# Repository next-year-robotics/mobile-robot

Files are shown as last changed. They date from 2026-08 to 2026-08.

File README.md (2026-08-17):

# Mobile Robot

An open mobile robot platform for perception, navigation, manipulation, and simulation.

> Work in progress.

## Structure

- `hardware/` — Mechanical and electronic design
- `firmware/` — STM32 and micro-ROS firmware
- `software/` — ROS 2 packages and higher-level software

## License

- Software and firmware: Apache-2.0
- Hardware: CERN-OHL-S-2.0
- Documentation: CC BY 4.0

See [LICENSE.md](./LICENSE.md).

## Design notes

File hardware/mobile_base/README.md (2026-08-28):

# Mobile-base geometry handoff

This directory is the hardware-side source of truth for the mobile-base frame,
drive-wheel, and camera placement measurements.

## Files

- `robot_params.yaml` is the compact parameter set intended for
  `software/ros_pkgs/mr_description/config/robot_params.yaml`.
- `cad_measurements.yaml` preserves the CAD origin, axis mapping, raw bounding
  boxes, derived transforms, measurement provenance, and deferred outputs.

The `mr_description` ROS package did not exist in this repository when this
handoff was created, so the integration-ready parameters are kept here until
that package is added.

## Coordinate contract

`base_footprint` is the floor point directly below the drive-axle midpoint.
Robot `+x` is forward, `+y` is left, and `+z` is up. `base_link` is 50 mm
directly above `base_footprint`, at the drive-axle height.

The confirmed transforms are:

```text
base_footprint -> base_link:      [0.000,  0.000, 0.050] m
base_link -> camera optical:      [0.250,  0.000, 0.360] m
base_link -> left wheel centre:   [0.000, +0.132, 0.000] m
base_link -> right wheel centre:  [0.000, -0.132, 0.000] m
camera mount RPY:                 [0.0, 0.0, 0.0] deg
```

The camera optical centre is therefore 410 mm above the floor and 250 mm in
front of the drive axle. It is centred laterally and looks straight forward.

## Derived-value checks

```text
camera z from base_link = 0.410 - 0.050 = 0.360 m
half wheel separation   = 0.264 / 2       = 0.132 m
wheel side inset        = 0.400 / 2 - 0.132 = 0.068 m
```

The measured “70 mm from each side” description is treated as rounded. The
existing 264 mm nominal wheel-separation contract is authoritative.

## CAD scope

The inspected STEP currently contains the aluminium frame, caster mounting
plates, and four casters. It does not yet contain the two driven wheels,
motors, C920, or camera mount. Its aluminium-frame bounding dimensions are
450 x 400 x 368 mm; these values are used only for the RViz placeholder shape.

No mount-face offset is needed for TF because the lens optical centre was
provided directly. Generate visual meshes only after the missing hardware is
added to the final CAD. A SolidWorks URDF export can then be used to
cross-check joint origins, but it should not replace the frame and link-name
contract recorded here.

## Odometry values are deliberately separate

`robot_params.yaml` contains the nominal geometry (`0.050 m` radius and
`0.264 m` separation). Do not overwrite the calibrated effective values in
`software/ros_pkgs/mr_base/config/base_params.yaml`; those values serve wheel
odometry and are expected to differ from the nominal hardware geometry.

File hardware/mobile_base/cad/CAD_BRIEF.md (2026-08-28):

# Mobile-base CAD brief

- Model: independently authored mobile-base assembly with an aluminium-extrusion
  cart, four simplified swivel casters, two nominal hinge-spring drive modules,
  and two reusable drive-wheel occurrences.
- Task type: new assembly and secondary RViz mesh exports.
- Inputs: `../cad_measurements.yaml`, `../robot_params.yaml`, the measured envelope
  of `C:/cad_work/cart/02_assembly/cart_sim.STEP`, and the geometry/interface
  parameters in
  `C:/cad_work/cart/hinge_spring_A_2026-07-31/hinge_spring_A_core.py`.
- Copyright boundary: the reference STEP is measured and visually inspected but
  never imported by this generator. All exported BREP and mesh geometry is built
  from fresh build123d primitives. Purchased-item detail is represented by new
  envelopes rather than copied supplier geometry.
- Units: millimetres in CAD and STL; URDF applies a `0.001` mesh scale.
- Mass: measured complete-robot mass is `9.8 kg`. The STEP remains a geometric
  master without artificial material densities; URDF link inertials allocate
  `8.6 kg` to the static chassis, `0.5 kg` to each drive wheel, and `0.2 kg` to
  the camera so the modeled total is exactly `9.8 kg`.
- Coordinate convention: preserve the measured STEP coordinate system. CAD
  `+x/+y/+z` equals robot forward/left/up. The CAD origin remains the aluminium
  frame plan origin. `base_link` is at `[-25, 0, 43.482687] mm` in CAD.
- Overall aligned-caster envelope: `515.529602 x 400 x 456.517313 mm`, with
  `z=[-6.517313, 450] mm`.
- Frame envelope: `450 x 400 x 368 mm`, with `z=[82, 450] mm`.
- Lower frame plane: the four internal `井`-pattern rails and the four outer
  lower perimeter rails share centre `z=92 mm`, bottom `z=82 mm`, and top
  `z=102 mm`; no internal rail is raised above the perimeter plane.
- Caster alignment: all four caster-wheel rolling planes are parallel to the
  powered drive wheels and robot `+X`; front caster yaws are `0 deg` and rear
  caster yaws are `180 deg` for a symmetric fore/aft pose.
- Drive geometry: wheel radius `50 mm`, width `24 mm`, and centres at
  `[-25, +132, 43.482687] mm` and `[-25, -132, 43.482687] mm`.
- Spring-module intent: keep the nominal 150 x 30 x 3 mm rocker, 95 mm
  pivot-to-wheel X distance, 50.2 mm installed spring length, and simplified
  hinge, motor, shaft, adapter, spring-seat, and travel-stop envelopes. The
  lateral shaft stack is adapted to the authoritative 264 mm wheel track.
- Positioning/mating: the cart is the fixed assembly root. Each wheel is placed
  with a source-level revolute mate about global `+Y`; the relation labels match
  `left_wheel_joint` and `right_wheel_joint`.
- Paths: `mobile_base_cad.py` -> `mobile_base_cad.step`;
  `cart_frame_mesh.py` -> `cart_frame_mesh.step` and the package STL;
  `drive_wheel_mesh.py` -> `drive_wheel_mesh.step` and the reusable package STL.
- Validation targets: labeled assembly, exact outer/static and wheel bounding
  boxes, 264 mm wheel-centre spacing, source-level revolute relationships,
  positive-volume solids, saved multi-view snapshots, and metre-scaled URDF
  mesh dimensions without a 1000x error.
- Assumptions: caster and purchased drive hardware are geometry envelopes, not
  manufacturing replicas. The C920 housing is omitted from CAD; URDF uses the
  permitted box envelope at the measured optical-centre transform.

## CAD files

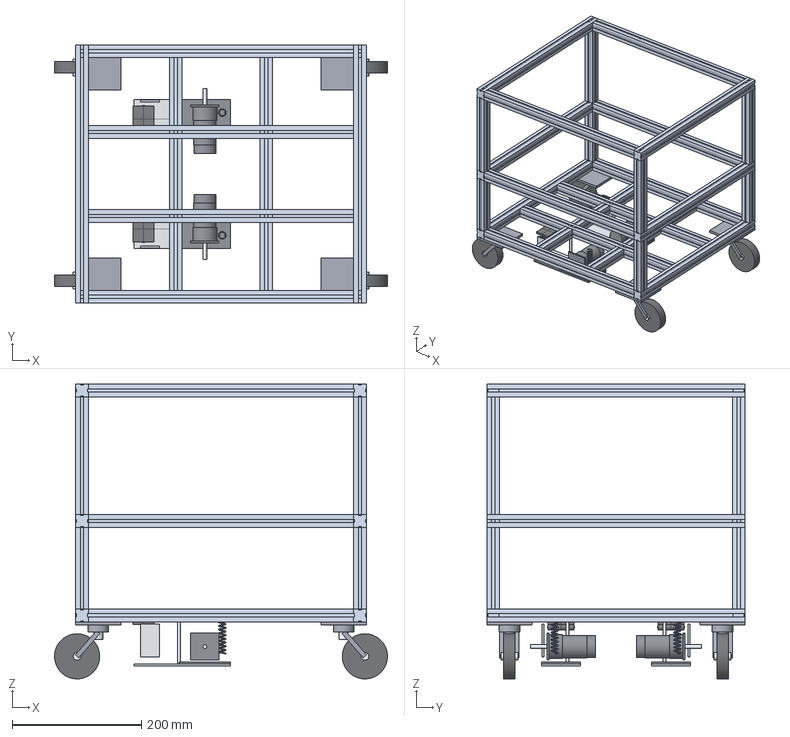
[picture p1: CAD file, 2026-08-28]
hardware/mobile_base/cad/cart_frame_mesh.step
515.5 x 400.0 x 456.5 mm
lower_left_x_rail
lower_right_x_rail
lower_front_y_rail
lower_rear_y_rail
upper_left_x_rail
upper_right_x_rail
upper_front_y_rail
upper_rear_y_rail
front_left_post
front_right_post
rear_left_post
rear_right_post
middle_left_x_rail
middle_right_x_rail
middle_front_y_rail
middle_rear_y_rail
lower_inner_x_rail_1
lower_inner_x_rail_2
lower_inner_y_rail_1
lower_inner_y_rail_2
front_left_caster_mount_plate
front_left_caster_swivel_bearing
front_left_caster_swivel_stem
front_left_caster_fork_arm_a
front_left_caster_fork_arm_b
front_left_caster_wheel
front_left_caster_axle
rear_right_caster_mount_plate
rear_right_caster_swivel_bearing
rear_right_caster_swivel_stem
rear_right_caster_fork_arm_a
rear_right_caster_fork_arm_b
rear_right_caster_wheel
rear_right_caster_axle
rear_left_caster_mount_plate
rear_left_caster_swivel_bearing
rear_left_caster_swivel_stem
rear_left_caster_fork_arm_a
rear_left_caster_fork_arm_b
rear_left_caster_wheel
rear_left_caster_axle
front_right_caster_mount_plate
front_right_caster_swivel_bearing
front_right_caster_swivel_stem
front_right_caster_fork_arm_a
front_right_caster_fork_arm_b
front_right_caster_wheel
front_right_caster_axle
left_rocker_1_150x30x3
left_rocker_2_150x30x3
left_hinge_1_fixed_leaf
left_hinge_1_moving_leaf
left_hinge_1_barrel
left_hinge_1_pin
left_hinge_2_fixed_leaf
left_hinge_2_moving_leaf
left_hinge_2_barrel
left_hinge_2_pin
left_WM12_60_spring_envelope
left_travel_stop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

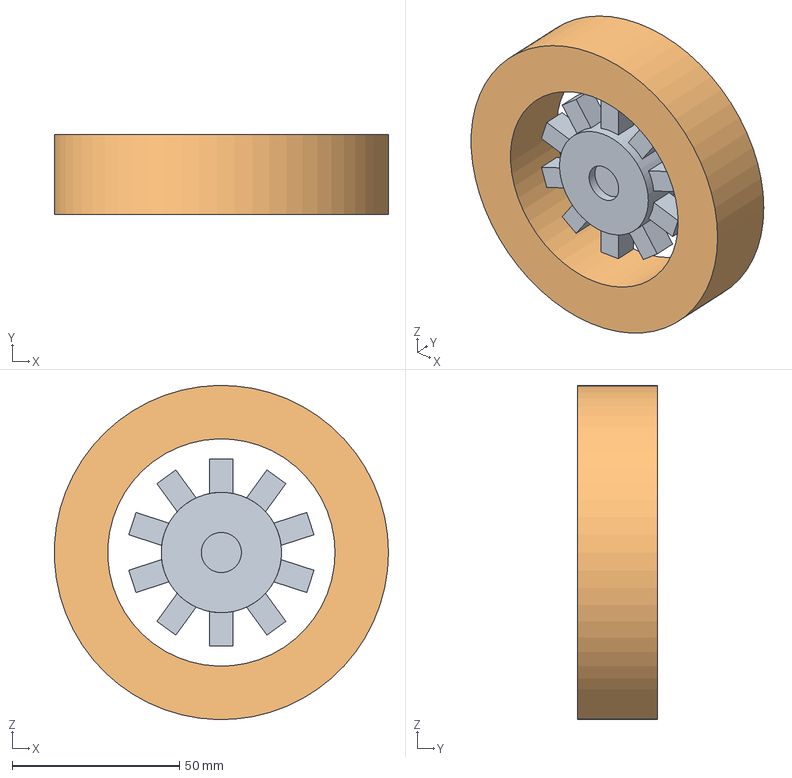
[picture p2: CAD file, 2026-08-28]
hardware/mobile_base/cad/drive_wheel_mesh.step
99.9 x 24.0 x 100.0 mm

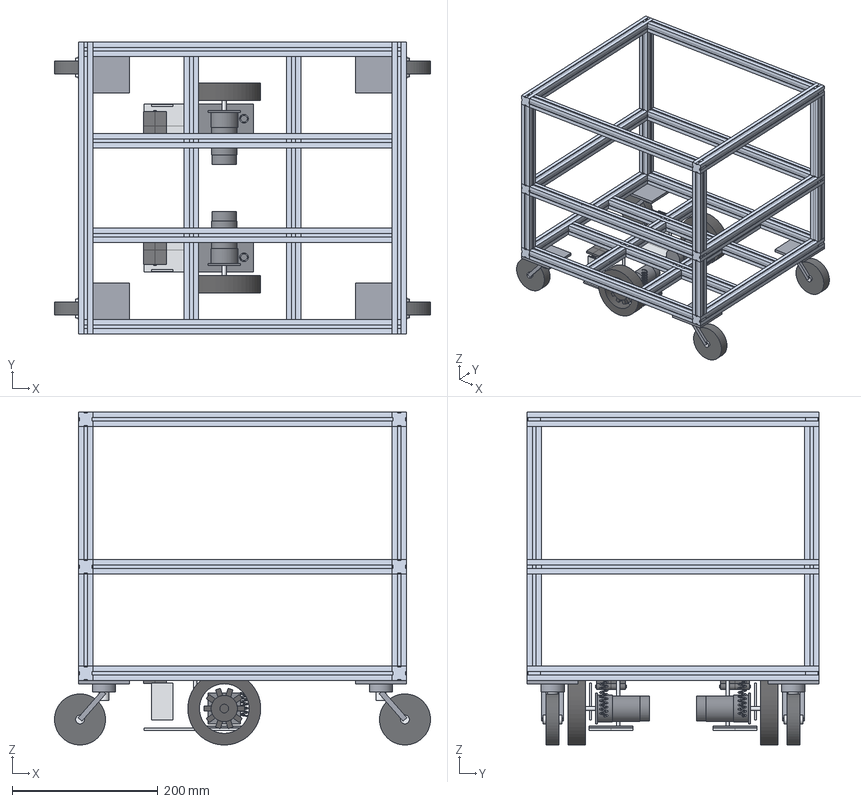
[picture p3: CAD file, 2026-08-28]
hardware/mobile_base/cad/mobile_base_cad.step
515.5 x 400.0 x 456.5 mm
lower_left_x_rail
lower_right_x_rail
lower_front_y_rail
lower_rear_y_rail
upper_left_x_rail
upper_right_x_rail
upper_front_y_rail
upper_rear_y_rail
front_left_post
front_right_post
rear_left_post
rear_right_post
middle_left_x_rail
middle_right_x_rail
middle_front_y_rail
middle_rear_y_rail
lower_inner_x_rail_1
lower_inner_x_rail_2
lower_inner_y_rail_1
lower_inner_y_rail_2
front_left_caster_mount_plate
front_left_caster_swivel_bearing
front_left_caster_swivel_stem
front_left_caster_fork_arm_a
front_left_caster_fork_arm_b
front_left_caster_wheel
front_left_caster_axle
rear_right_caster_mount_plate
rear_right_caster_swivel_bearing
rear_right_caster_swivel_stem
rear_right_caster_fork_arm_a
rear_right_caster_fork_arm_b
rear_right_caster_wheel
rear_right_caster_axle
rear_left_caster_mount_plate
rear_left_caster_swivel_bearing
rear_left_caster_swivel_stem
rear_left_caster_fork_arm_a
rear_left_caster_fork_arm_b
rear_left_caster_wheel
rear_left_caster_axle
front_right_caster_mount_plate
front_right_caster_swivel_bearing
front_right_caster_swivel_stem
front_right_caster_fork_arm_a
front_right_caster_fork_arm_b
front_right_caster_wheel
front_right_caster_axle
left_rocker_1_150x30x3
left_rocker_2_150x30x3
left_hinge_1_fixed_leaf
left_hinge_1_moving_leaf
left_hinge_1_barrel
left_hinge_1_pin
left_hinge_2_fixed_leaf
left_hinge_2_moving_leaf
left_hinge_2_barrel
left_hinge_2_pin
left_WM12_60_spring_envelope
left_travel_stop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

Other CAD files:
software/ros_pkgs/mr_description/meshes/cart_frame.stl
software/ros_pkgs/mr_description/meshes/drive_wheel.stl

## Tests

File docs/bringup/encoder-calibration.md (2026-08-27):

# 엔코더 브링업 및 바퀴 틱 수 실측

완료: 2026-08-20

## 1. 목적

1. TIM2/TIM3 encoder mode가 잘 동작하는가?
2. 바퀴 1회전당 틱 수(`ticks_per_wheel_revolution`)는 실제로 얼마인가?

## 2. 구성

| 항목 | 값 |
|---|---|
| 모터 | JGB37-520 × 2 |
| 엔코더 | 홀 방식, 채널당 공칭 11 pulse/rev (모터축 기준) |
| 왼쪽 A/B | PA6 / PA7 — TIM3 encoder |
| 오른쪽 A/B | PA0 / PA1 — TIM2 encoder |
| Encoder Mode | TI1 and TI2 (×4 체배) |
| ARR | 65535 (두 타이머 모두 16-bit 범위로 통일) |
| 입력 필터 IC1F/IC2F | 4 |
| A/B 외부 풀업 | 10 kΩ → 3V3 (4개) |
| 엔코더 전원 | NUCLEO 3V3 실측 3.307 V |

## 3. 동작 검증

| 시험 | 기대값 | 실측 | 결과 |
|---|---|---|---|
| 정지 60초 자발 카운트 | 0 tick | 좌 0 / 우 0 | **PASS** |
| 왼쪽만 회전 시 오른쪽 변화 | 0 tick | 0 | **PASS** |
| 오른쪽만 회전 시 왼쪽 변화 | 0 tick | 0 | **PASS** |
| 왼쪽 정/역 1회전 복귀 | ±2 tick | 0 tick | **PASS** |
| 오른쪽 정/역 1회전 복귀 | ±2 tick | 1 tick | **PASS** |

전진 방향 원시 부호는 왼쪽 +, 오른쪽 - 

## 4. 바퀴 10회전 틱 수 실측

바퀴에 표시점을 두고 정확히 10회전시켜 누적 틱 차이를 잰다.

| 바퀴 | 방향 | 1 | 2 | 3 | 4 | 5 | 평균 tick/rev | 표준편차 | RSD |
|---|---|---:|---:|---:|---:|---:|---:|---:|---:|
| 왼쪽 | 정방향 | 2473.9 | 2473.8 | 2476.2 | 2474.7 | 2475.8 | **2474.88** | 1.09 | **0.044 %** |
| 왼쪽 | 역방향 | 2482.0 | 2480.7 | 2475.3 | 2476.7 | 2475.9 | **2478.12** | 3.03 | **0.122 %** |
| 오른쪽 | 정방향 | 2473.7 | 2475.0 | 2473.1 | 2475.7 | 2474.3 | **2474.36** | 1.03 | **0.042 %** |
| 오른쪽 | 역방향 | 2475.6 | 2474.1 | 2475.5 | 2474.6 | 2473.6 | **2474.68** | 0.87 | **0.035 %** |

### 확정값

| 항목 | 값 |
|---|---|
| `ticks_per_wheel_revolution` 왼쪽 | **2476.5** |
| `ticks_per_wheel_revolution` 오른쪽 | **2474.5** |
| 좌우 통합 | **2475.5** |

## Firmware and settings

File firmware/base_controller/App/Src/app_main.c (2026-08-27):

/**
  ******************************************************************************
  * @file    app_main.c
  * @brief   LegacyIoTask orchestration. ASCII 수신/파싱/ACK/telemetry만 맡는다.
  * @note    정책·파싱 계산은 전부 순수 모듈에 있다. 이 파일은 순서만 정한다.
  *          레지스터는 platform_stm32 adapter를 통해서만 만진다. TIM1/CCR/MOE는
  *          여기서 건드리지 않는다. 모터 출력의 정상 경로 소유자는 ControlTask다.
  *
  *          한 바퀴의 순서는 안전이 먼저다. 자세한 단계는 app_step()에 적어 두었다.
  ******************************************************************************
  */
#include "app_main.h"

#include "app_config.h"
#include "app_link.h"
#include "control_ack.h"
#include "control_types.h"
#include "line_builder.h"
#include "motor_output.h"
#include "motor_safety.h"
#include "platform_stm32.h"
#include "protocol_ascii.h"
#include "rx_ring.h"

static rx_ring_t  g_rx;
static protocol_t g_proto;

/* 송신 버퍼. 송신은 전부 이 task에서만 하므로 하나를 돌려 쓴다. */
static char g_tx_buffer[TX_LINE_CAP];

static uint32_t g_last_report_ms;

/* `spd` 텔레메트리 스위치. 기본은 꺼짐이다. 이 줄을 해석하지 않는 호스트 도구가 있으므로
   기본으로 켜 두면 그쪽 파싱이 깨진다. */
static bool g_spd_enabled;

/* ControlTask status에서 관측한 워치독 만료 edge. 변화가 보일 때만 `wd` 한 줄이 나간다. */
static uint32_t g_wd_seq_seen;

/* 발행한 command sequence. 0은 "없음"이라 1부터 쓴다. */
static uint32_t g_cmd_seq;

/* ISR이 올리고 task가 관측하는 계측값. */
static volatile uint32_t g_uart_error_count;
static volatile uint32_t g_uart_error_last;
static volatile uint32_t g_rx_rearm_fail_isr;
static volatile uint32_t g_rx_overflow_count;
/* RX overflow/UART error마다 ISR이 증가시킨다. ISR은 동시에 ControlTask에 urgent
   STOP도 건다. task는 epoch 변화를 보면 링을 통째로 비우고 다음 개행까지 parser를
   poison한다. */
static volatile uint32_t g_rx_fault_epoch;
static uint32_t g_rx_fault_seen;
static uint32_t g_rx_rearm_fail_run;
static uint32_t g_tx_fail_count;
static uint32_t g_tx_build_fail_count;
static uint32_t g_cmd_accepted_count;
static uint32_t g_cmd_timeout_count;
static uint32_t g_cmd_seq_mismatch_count;
static uint32_t g_cmd_rejected_count;

/* ------------------------------------------------------------------------- */
/* ISR 진입점                                                                 */
/* ------------------------------------------------------------------------- */

void app_on_rx_byte(uint8_t byte)
{
  if (!rx_ring_push(&g_rx, byte))
  {
    g_rx_overflow_count++;
    g_rx_fault_epoch++;
    /* CCR을 여기서 직접 쓰지 않는다. 최고 우선순위 ControlTask가 ISR 복귀 즉시
       선점해 출력을 0으로 만든다. */
    app_link_urgent_stop_from_isr(MOTOR_FAULT_NONE);
    /* 링 폐기와 parser poison은 IO task의 일이다. poll timeout을 기다리지 않고
       바로 깨워 재동기화를 앞당긴다. */
    app_link_notify_io_from_isr();
    return;
  }

  /* 프레임 경계에서만 깨운다. 230400 8N1에서 바이트마다 깨우면 notification이 초당
     2만 번을 넘는다. 그만큼은 전부 ISR/문맥전환 오버헤드가 된다. */
  if (byte == (uint8_t)'\n')
  {
    app_link_notify_io_from_isr();
  }
}

void app_on_uart_error(uint32_t error_code)
{
  /* HAL의 ORE 복구/재무장 경계에서는 ErrorCode가 이미 clear된 callback이 뒤따를 수
     있다. 마지막 유효 FE/NE/ORE 진단값을 0으로 덮어쓰지 않는다. */
  if (error_code != 0U)
  {
    g_uart_error_last = error_code;
  }
  g_uart_error_count++;
  g_rx_fault_epoch++;
  app_link_urgent_stop_from_isr(MOTOR_FAULT_NONE);
  app_link_notify_io_from_isr();
}

void app_on_rx_rearm_failed(void)
{
  g_rx_rearm_fail_isr++;
}

/* ------------------------------------------------------------------------- */
/* 송신                                                                       */
/* ------------------------------------------------------------------------- */

/**
  * @brief  한 줄을 조립해 내보낸다. 실패는 계측하고 안전 상태로 넘어간다.
  * @note   빌더가 capacity를 실제로 검사하므로 넘치는 줄은 송신되지 않는다. 송신
  *         실패는 치명 경로다. platform_motor_kill()은 RTOS와 무관하게 즉시 부를 수
  *         있는 유일한 예외다. 그 뒤 ControlTask에도 fault를 래치시켜 이후 명령을
  *         `err`로 만든다.
  */
static void send_line(const char *tag, const int64_t *values, size_t count)
{
  size_t offset;
  size_t length;

  if (!line_build(g_tx_buffer, sizeof(g_tx_buffer), tag, values, count,
                  &offset, &length))
  {
    g_tx_build_fail_count++;
    platform_motor_kill();
    app_link_urgent_stop(MOTOR_FAULT_TX_BUILD);
    return;
  }

  if (!platform_uart_send(&g_tx_buffer[offset], length))
  {
    g_tx_fail_count++;
    platform_motor_kill();
    app_link_urgent_stop(MOTOR_FAULT_TX);
  }
}

static void send_err(uint32_t now_ms)
{
  int64_t value = (int64_t)now_ms;

  send_line("err", &value, 1U);
}

/* ------------------------------------------------------------------------- */
/* 수신                                                                       */
/* ------------------------------------------------------------------------- */

/** @brief ISR이 새 RX 손상을 기록했는가 (아직 동기화하지 않은 epoch가 있는가). */
static bool rx_fault_pending(void)
{
  return g_rx_fault_epoch != g_rx_fault_seen;
}

/**
  * @brief  ISR이 남긴 손상 신호를 프로토콜 상태기계에 반영한다.
  * @note   기존 큐에는 오류 위치보다 앞선 newline이 있을 수 있다. 큐 전체를 버린 뒤
  *         fault 이후 새로 도착한 newline에서만 parser가 재동기화되게 한다.
  */
static bool sync_rx_faults(void)
{
  uint32_t epoch;
  uint32_t critical_state = platform_critical_enter();

  epoch = g_rx_fault_epoch;
  if (epoch == g_rx_fault_seen)
  {
    platform_critical_exit(critical_state);
    return false;
  }

  /* 오류 바이트보다 앞에 있던 newline에서 너무 일찍 재동기화되는 일을 막기 위해
     현재 큐를 전부 버린다. critical section 안이라 ISR 생산자와 head/tail이 섞이지 않는다. */
  rx_ring_discard_all(&g_rx);
  g_rx_fault_seen = epoch;
  platform_critical_exit(critical_state);

  protocol_poison(&g_proto);

  /* ISR이 이미 걸었지만 여기서 한 번 더 확정한다. 멱등이다. task 문맥에서 뒤늦게
     발견한 epoch에도 정지가 반드시 따라붙게 한다. */
  app_link_urgent_stop(MOTOR_FAULT_NONE);
  return true;
}

/**
  * @brief  수신이 풀려 있으면 다시 건다. ErrorCallback이 놓친 경우의 그물이다.
  */
static void rx_rearm_if_needed(void)
{
  if (platform_uart_rx_is_armed())
  {
    g_rx_rearm_fail_run = 0U;
    return;
  }

  if (platform_uart_rx_arm())
  {
    g_rx_rearm_fail_run = 0U;
    return;
  }

  g_rx_rearm_fail_run++;
  if (g_rx_rearm_fail_run >= CMD_RX_REARM_FAIL_LIMIT)
  {
    platform_motor_kill();
    app_link_urgent_stop(MOTOR_FAULT_RX_REARM);
  }
}

/** @brief ASCII 명령 종류를 ControlTask의 지령 종류로 옮긴다. */
static control_cmd_kind_t control_kind_of(proto_cmd_kind_t kind)
{
  if (kind == PROTO_CMD_DUTY)
  {
    return CONTROL_CMD_DUTY;
  }
  if (kind == PROTO_CMD_VEL)
  {
    return CONTROL_CMD_VEL;
  }
  return CONTROL_CMD_STOP;
}

/**
  * @brief  수락된 명령을 ControlTask에 넘기고 적용 결과를 받은 뒤에만 ACK한다.
  * @note   `ok`는 "queue에 넣었다"가 아니라 "이 sequence의 값이 CCR에 반영됐다"는
  *         뜻이다. 그래서 stop도 출력이 0이 된 뒤에 ACK된다. `spd`만 예외다.
  *         ControlTask로 가지 않는 설정 명령이라 여기서 끝난다.
  */
static void command_accept(const proto_command_t *cmd, uint32_t now_ms)
{
  control_command_t out;
  control_apply_result_t result;
  control_ack_t ack;
  bool received;
  int64_t values[3];
  uint32_t critical_state;

  out.seq = g_cmd_seq + 1U;
  out.kind = control_kind_of(cmd->kind);
  out.left = cmd->left;
  out.right = cmd->right;
  out.accepted_ms = now_ms;
  out.deadline_ms = now_ms + CMD_WATCHDOG_MS;

  /* RX fault ISR이 판정과 게시 사이에 끼어 손상된 프레임의 명령이 나가지 못하게
     짧게 막는다. 여기서 걸리면 이 줄은 실행하지 않는다. */
  critical_state = platform_critical_enter();
  if (rx_fault_pending())
  {
    platform_critical_exit(critical_state);
    (void)sync_rx_faults();
    send_err(now_ms);
    return;
  }
  platform_critical_exit(critical_state);

  if (cmd->kind == PROTO_CMD_SPD)
  {
    /* 설정 명령이다. 워치독을 먹이지 않는다. 설정을 반복해서 모터를 계속 살려두는
       경로를 막기 위해서다. ControlTask의 mailbox에도 들어가지 않으므로 command
       sequence도 소비하지 않는다. ACK 형식은 그대로 두고 상태값 하나를 두 번
       싣는다. */
    g_spd_enabled = (cmd->left != 0);
    values[0] = (int64_t)now_ms;
    values[1] = (int64_t)cmd->left;
    values[2] = (int64_t)cmd->left;
    send_line("ok", values, 3U);
    return;
  }

  g_cmd_seq = out.seq;

  if (!app_link_post_command(&out))
  {
    send_err(now_ms);
    return;
  }
  g_cmd_accepted_count++;

  received = app_link_wait_applied(out.seq, CMD_APPLY_TIMEOUT_MS, &result);

  /* 적용된 뒤에 손상이 들어왔다면 출력은 이미 다시 0이다. 그 duty를 ok로 보고하지 않는다. */
  ack = control_ack_decide(received, out.seq, &result, rx_fault_pending());

  switch (ack)
  {
    case CONTROL_ACK_OK:
      values[0] = (int64_t)result.applied_ms;
      values[1] = (int64_t)result.left;
      values[2] = (int64_t)result.right;
      send_line("ok", values, 3U);
      return;

    case CONTROL_ACK_ERR_TIMEOUT:
      g_cmd_timeout_count++;
      break;

    case CONTROL_ACK_ERR_SEQ:
      g_cmd_seq_mismatch_count++;
      break;

    case CONTROL_ACK_ERR_REJECTED:
    case CONTROL_ACK_ERR_RX_FAULT:
    default:
      g_cmd_rejected_count++;
      break;
  }

  send_err(now_ms);
}

/**
  * @brief  수신 링을 소비하며 줄이 완성될 때마다 해석한다.
  * @note   바이트 수와 줄 수에 명시적 상한이 있다. 호스트가 짧은 오류 줄을 최고속으로
  *         퍼부어도 이 함수가 telemetry나 워치독 통지를 굶길 수 없다. 낮은 우선순위라
  *         100 Hz ControlTask를 지연시킬 수도 없다.
  */
static void command_poll(uint32_t now_ms)
{
  uint32_t bytes = 0U;
  uint32_t lines = 0U;

  while ((bytes < CMD_POLL_MAX_BYTES) && (lines < CMD_POLL_MAX_LINES))
  {
    proto_command_t cmd;
    proto_event_t event;
    uint8_t byte;

    if (sync_rx_faults())
    {
      /* 링 전체를 비웠다. 다음 loop에서 fault 이후 새 바이트를 기다린다. */
      break;
    }

    if (!rx_ring_pop(&g_rx, &byte))
    {
      break;
    }
    bytes++;

    event = protocol_push(&g_proto, (char)byte, &cmd);
    if (event == PROTO_EVENT_NONE)
    {
      continue;
    }

    lines++;
    if (event == PROTO_EVENT_COMMAND)
    {
      command_accept(&cmd, now_ms);
    }
    else
    {
      /* 거절한 줄은 워치독을 갱신하지 않는다. */
      send_err(now_ms);
    }
  }
}

/* ------------------------------------------------------------------------- */
/* 진입점                                                                     */
/* ------------------------------------------------------------------------- */

bool app_init(void)
{
  /* 수신 인터럽트가 살아나기 전에 소비 측 상태를 확정한다. */
  rx_ring_init(&g_rx);
  protocol_init(&g_proto);
  g_uart_error_count = 0U;
  g_uart_error_last = 0U;
  g_rx_rearm_fail_isr = 0U;
  g_rx_overflow_count = 0U;
  g_rx_fault_epoch = 0U;
  g_rx_fault_seen = 0U;
  g_rx_rearm_fail_run = 0U;
  g_tx_fail_count = 0U;
  g_tx_build_fail_count = 0U;
  g_cmd_accepted_count = 0U;
  g_cmd_timeout_count = 0U;
  g_cmd_seq_mismatch_count = 0U;
  g_cmd_rejected_count = 0U;
  g_cmd_seq = 0U;
  g_wd_seq_seen = 0U;
  g_spd_enabled = false;

  if (!platform_init())
  {
    return false;
  }

  g_last_report_ms = platform_now_ms();
  return true;
}

void app_step(void)
{
  uint32_t now_ms = platform_now_ms();
  control_status_t status;

  /* 1. 안전이 먼저다. RX 손상이 있으면 이전 큐를 폐기하고 출력 0을 확정시킨다. */
  (void)sync_rx_faults();

  /* 2. 링크 유지. */
  if (g_rx_rearm_fail_isr != 0U)
  {
    g_rx_rearm_fail_isr = 0U;
    g_rx_rearm_fail_run++;
  }
  rx_rearm_if_needed();

  /* 3. 상한이 있는 명령 처리. */
  command_poll(now_ms);

  if (!app_link_get_status(&status))
  {
    return;
  }

  /* 4. 워치독 만료 통지. ControlTask가 출력 0을 반영한 뒤에만 edge가 올라간다. */
  if (status.wd_seq != g_wd_seq_seen)
  {
    int64_t value = (int64_t)status.wd_ms;

    g_wd_seq_seen = status.wd_seq;
    send_line("wd", &value, 1U);
  }

  /* 5. 50 Hz 텔레메트리. 누적 int64 의미를 그대로 유지한다. */
  if ((uint32_t)(now_ms - g_last_report_ms) >= TICKS_REPORT_PERIOD_MS)
  {
    int64_t values[5];

    g_last_report_ms += TICKS_REPORT_PERIOD_MS;
    values[0] = (int64_t)now_ms;
    values[1] = status.ticks_left;
    values[2] = status.ticks_right;
    send_line("ticks", values, 3U);

    /* 튜닝용 스트림. 목표와 포화 플래그는 넣지 않는다. 목표는 ok가 이미 알려줬다.
       적분기와 포화는 SWD로 g_rtos_metrics에서 본다. 값을 늘리면 최악 줄이
       TX_LINE_CAP을 넘어 UART_TX_TIMEOUT_MS 여유까지 다시 잡아야 한다. */
    if (g_spd_enabled)
    {
      values[1] = (int64_t)status.measured_tps_left;
      values[2] = (int64_t)status.duty_left_pm;
      values[3] = (int64_t)status.measured_tps_right;
      values[4] = (int64_t)status.duty_right_pm;
      send_line("spd", values, 5U);
    }
  }
}

void app_get_io_metrics(app_io_metrics_t *out)
{
  out->rx_overflow_count = g_rx_overflow_count;
  out->uart_error_count = g_uart_error_count;
  out->uart_error_last = g_uart_error_last;
  out->rx_rearm_fail_count = g_rx_rearm_fail_run;
  out->tx_fail_count = g_tx_fail_count;
  out->tx_build_fail_count = g_tx_build_fail_count;
  out->cmd_accepted_count = g_cmd_accepted_count;
  out->cmd_timeout_count = g_cmd_timeout_count;
  out->cmd_seq_mismatch_count = g_cmd_seq_mismatch_count;
  out->cmd_rejected_count = g_cmd_rejected_count;
}

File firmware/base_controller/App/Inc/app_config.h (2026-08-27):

/**
  ******************************************************************************
  * @file    app_config.h
  * @brief   펌웨어 확정 상수. HAL/RTOS에 의존하지 않는다.
  * @note    순수 모듈과 STM32 adapter가 함께 쓰는 헤더다. 여기에 HAL 헤더나
  *          main.h를 들이면 host 단위 테스트가 깨진다.
  ******************************************************************************
  */
#ifndef APP_CONFIG_H
#define APP_CONFIG_H

#include <stdint.h>

/* ---- 주기 ---- */
#define LD2_TOGGLE_PERIOD_MS      500U
#define ENCODER_SAMPLE_PERIOD_MS   10U  /* == CONTROL_PERIOD_MS. ControlTask가 샘플한다. */
#define TICKS_REPORT_PERIOD_MS     20U  /* 50 Hz */

/* ---- RTOS 실행 구조 ---- */

/* TIM6가 만드는 control tick. .ioc의 TIM6 8399/99(84 MHz/8400/100)와 같아야 한다. */
#define CONTROL_RATE_HZ           100U
#define CONTROL_PERIOD_MS          10U

/* native FreeRTOS numeric priority다. FreeRTOSConfig.h의 configMAX_PRIORITIES=56은
   ST CMSIS-RTOS v2 wrapper의 compile-time 요구값일 뿐이고 아래 값과 무관하다. */
#define TASK_PRIO_CONTROL           5U
#define TASK_PRIO_HEALTH            4U
#define TASK_PRIO_LEGACY_IO         2U

/* 길이 단위는 StackType_t word다 (1 word = 4 B). CMSIS osThreadAttr_t의 stack_size는
   byte라 값이 다르다. 이 프로젝트는 task를 native xTaskCreateStatic으로만 만들므로
   전부 word로 읽는다. */
#define TASK_STACK_WORDS_CONTROL   384U  /* 1,536 B */
#define TASK_STACK_WORDS_HEALTH    256U  /* 1,024 B */
#define TASK_STACK_WORDS_IO        512U  /* 2,048 B */
#define TASK_STACK_WORDS_IDLE      256U  /* 1,024 B */

#define HEALTH_PERIOD_MS           50U

/* HIL 전용 build option. 평소에는 0이다. CMake의 -DIWDG_STALL_TEST=ON일 때만
   ControlTask 정지 주입 hook을 컴파일한다. */
#ifndef IWDG_STALL_TEST
#define IWDG_STALL_TEST              0
#endif

/* HIL 전용 build option. CMake의 -DU3_SMOKE_TEST=ON일 때만 SmokeTask와 u3_smoke.c가
   들어간다. production image에는 USART1로 한 바이트도 나가지 않는다. */
#ifndef U3_SMOKE_TEST
#define U3_SMOKE_TEST                0
#endif

/* SmokeTask는 가장 낮은 우선순위다. 시험 트래픽이 제어·관측·레거시 IO 중 어느 것도
   지연시킬 수 없어야 "제어는 그대로"라는 전제가 성립한다. */
#define TASK_PRIO_SMOKE             1U
#define TASK_STACK_WORDS_SMOKE    384U  /* 1,536 B */

/* USART1 DMA 링을 긁는 주기. 보드레이트가 올라가도 이 주기만 지키면 링이 넘치지 않는다. */
#define U3_SMOKE_POLL_MS            1U

/* T 스트림 주기. `/joint_states` 계약과 같은 50 Hz로 두어 실제 부하를 흉내 낸다. */
#define U3_STREAM_PERIOD_MS        20U

/* 한 주기에 긁어 갈 최대 바이트. 3 Mbaud의 1 ms 분량(약 300 B)보다 커야 한다. */
#define U3_SMOKE_READ_CHUNK       512U

/* 보드레이트 스윕 안전망. 속도를 바꾼 뒤 이 시간 안에 유효한 줄이 하나도 오지 않으면
   기본 속도로 되돌린다. 되돌리지 않으면 실패한 단계마다 보드 리셋이 필요하다.

   `.ioc`의 `USART1.BaudRate`와 같아야 한다. 갈리면 자동 복귀가 엉뚱한 속도로 가서
   링크가 살아나지 않는다. */
#define U3_BAUD_DEFAULT        921600U
#define U3_BAUD_REVERT_MS        5000U
/* ACK를 보낸 뒤 호스트가 자기 포트를 다시 여는 데 주는 시간. */
#define U3_BAUD_ACK_SETTLE_MS      50U

/* LegacyIoTask는 개행 notification으로 깨어난다. 이 timeout은 telemetry/워치독
   통지/재무장을 위한 그물이다. 명령 지연이 아니라 주기 작업의 jitter 상한이다. */
#define LEGACY_IO_POLL_MS           2U

/* ControlTask가 명령을 반영하고 결과를 돌려줄 때까지 기다리는 상한. ControlTask는
   최고 우선순위라 정상적으로는 게시 즉시 선점해 결과가 이미 와 있다. 이 시간을
   넘기면 적용 근거가 없으므로 err다. */
#define CMD_APPLY_TIMEOUT_MS       30U

/* HealthTask가 control heartbeat 정체로 보고 IWDG refresh를 중단하는 한계. */
#define HEALTH_HEARTBEAT_STALL_MS 100U

/* ---- micro-ROS ---- */

/* CMake의 -DMICRO_ROS=ON일 때만 MicroRosTask와 libmicroros.a가 들어간다.
   U3_SMOKE_TEST와는 동시에 켤 수 없다. 둘 다 USART1의 소유자를 자처한다. */
#ifndef MICRO_ROS
#define MICRO_ROS                    0
#endif

/* ControlTask보다 낮고 LegacyIoTask보다 높다.
     - ControlTask(P5)보다 낮아야 하는 이유: micro-ROS는 blocking 송신과 상한이
       분명치 않은 executor를 품고 있다. 100 Hz 제어를 막을 수 없어야 한다.
     - HealthTask(P4)보다 낮아야 하는 이유: reconnect storm 중에도 IWDG는 계속
       먹어야 한다.
     - LegacyIoTask(P2)보다 높아야 하는 이유: 이제 실제 주행 명령이 이 경로로
       온다. 디버그용 ASCII 텔레메트리가 /cmd_vel을 밀어내면 안 된다. */
#define TASK_PRIO_MICRO_ROS         3U

/* rcl/rclc의 호출 깊이가 있어 LegacyIoTask보다 넉넉히 잡는다. 실제 사용량은
   HealthTask가 재는 stack high-water mark로 확인하고 줄인다. */
#define TASK_STACK_WORDS_MICRO_ROS 1536U  /* 6,144 B */

/* MicroRosTask 한 바퀴의 상한. 이 주기가 곧 `/joint_states` 타이밍 분해능이다. */
#define MICRO_ROS_POLL_MS            2U

/* 계약이 정한 발행 주기. */
#define JOINT_STATES_PERIOD_MS      20U  /* 50 Hz */
#define BASE_STATUS_PERIOD_MS      100U  /* 10 Hz */

/* `/joint_states` stamp를 되돌릴 수 있는 최대 나이. 정상값은 한 control cycle
   (10 ms) 이내다. 여기에 닿았다면 ControlTask가 멈춘 것이므로 더 과거로 보내는
   대신 상한에서 자르고 계수한다. */
#define JOINT_STATES_MAX_AGE_MS    100

/* micro-ROS 전용 pool. FreeRTOS heap도 newlib malloc도 쓰지 않는 이유는 static_pool.h에
   있다. 실사용량의 여러 배로 잡아 둔 값이다. 딱 맞게 깎으면 토픽을 하나 늘리는 순간
   `alloc_fail`이 뜨는데, 그 실패는 "엔티티 생성 실패 -> 재접속 반복"으로 나타나 원인을
   엉뚱하게 트랜스포트에서 찾게 된다. 토픽을 늘렸다면 `mr_pool_free_min`으로 여유를
   다시 확인한다. */
#define MICRO_ROS_POOL_BYTES      8192U  /* 8 KiB */

/* custom transport read의 폴링 주기. platform_uart1의 DMA 링을 긁는 간격이며
   U3_SMOKE_POLL_MS와 같은 근거다(링 2048 B는 921600에서 22 ms 분량). */
#define MICRO_ROS_TRANSPORT_POLL_MS  1U
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

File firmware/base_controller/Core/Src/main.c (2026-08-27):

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
/* Includes ------------------------------------------------------------------*/
#include "main.h"
#include "cmsis_os.h"
#include "dma.h"
#include "iwdg.h"
#include "tim.h"
#include "usart.h"
#include "gpio.h"

/* USER CODE BEGIN Includes */
#include "app_main.h"
#include "platform_stm32.h"
#include "rtos_app.h"

/* USER CODE END Includes */

/* USER CODE BEGIN PD */
/* 애플리케이션 상수는 전부 App/Inc/app_config.h에 있다. */

/* USER CODE END PD */


/* USER CODE BEGIN PV */
/* 애플리케이션 상태는 전부 App/Src/app_main.c에 있다. */

/* USER CODE END PV */

void SystemClock_Config(void);
void MX_FREERTOS_Init(void);
/* USER CODE BEGIN 0 */
/* 파서/빌더/모터 정책/워치독은 App/에, HAL 콜백은 App/Src/platform_stm32.c에 있다. */

/* USER CODE END 0 */

/**
  * @brief  The application entry point.
  * @retval int
  */
int main(void)
{

  /* MCU Configuration--------------------------------------------------------*/

  /* Reset of all peripherals, Initializes the Flash interface and the Systick. */
  HAL_Init();

  /* USER CODE BEGIN Init */
  /* reset 원인은 RCC flag를 지우기 전에 보존한다. debugger halt 중에는 IWDG를
     멈춰 SWD 계측이 reset을 유발하지 않게 한다. 둘 다 IWDG 시작보다 앞선다. */
  platform_boot_snapshot_reset_flags();
  __HAL_DBGMCU_FREEZE_IWDG();

  /* USER CODE END Init */

  /* Configure the system clock */
  SystemClock_Config();

  /* Initialize all configured peripherals */
  MX_GPIO_Init();
  MX_DMA_Init();
  MX_USART2_UART_Init();
  MX_TIM2_Init();
  MX_TIM3_Init();
  MX_TIM1_Init();
  MX_TIM6_Init();
  MX_IWDG_Init();
  MX_USART1_UART_Init();
  /* USER CODE BEGIN 2 */
  /* TIM1 ARR 대조, CCR 0 확정, PWM/엔코더 기동, DWT 활성화까지 여기서 끝난다.
     인터럽트 원(USART2 RX, TIM6)은 여기서 켜지 않는다. task handle과 static
     mailbox가 생긴 뒤 각 소유 task의 첫머리에서 시작한다. */
  if (!app_init())
  {
    Error_Handler();
  }

  /* USER CODE END 2 */

  /* Init scheduler */
  osKernelInitialize();  /* Call init function for freertos objects (in cmsis_os2.c) */
  MX_FREERTOS_Init();

  /* Start scheduler */
  osKernelStart();

  /* We should never get here as control is now taken by the scheduler */

  /* Infinite loop */
  /* USER CODE BEGIN WHILE */
  while (1)
  {
    /* scheduler가 돌아왔다면 커널을 시작하지 못한 것이다. 애플리케이션은
       ControlTask/LegacyIoTask 안에서 도므로 여기서 할 일이 없다. 모터를 끊고
       멈춘다. */
    Error_Handler();
    /* USER CODE END WHILE */

    /* USER CODE BEGIN 3 */
  }
  /* USER CODE END 3 */
}

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
/**
  * @brief  Period elapsed callback in non blocking mode
  * @note   This function is called  when TIM7 interrupt took place, inside
  * HAL_TIM_IRQHandler(). It makes a direct call to HAL_IncTick() to increment
  * a global variable "uwTick" used as application time base.
  * @param  htim : TIM handle
  * @retval None
  */
void HAL_TIM_PeriodElapsedCallback(TIM_HandleTypeDef *htim)
{
  if (htim->Instance == TIM7)
  {
    HAL_IncTick();
  }
}

/**
  * @brief  This function is executed in case of error occurrence.
  * @retval None
  */
void Error_Handler(void)
{
  /* USER CODE BEGIN Error_Handler_Debug */
  /* 여기서 멈추는 순간 모터가 돌고 있을 수 있다. 소프트웨어 워치독은 task가 돌아야
     동작하므로 무한 루프에 들어가기 전에 직접 끈다. */
  platform_motor_kill();

  /* User can add his own implementation to report the HAL error return state */
  __disable_irq();
  while (1)
  {
  }
  /* USER CODE END Error_Handler_Debug */
}
#ifdef USE_FULL_ASSERT
/**
  * @brief  Reports the name of the source file and the source line number
  *         where the assert_param error has occurred.
  * @param  file: pointer to the source file name
  * @param  line: assert_param error line source number
  * @retval None
  */
void assert_failed(uint8_t *file, uint32_t line)
{
  /* USER CODE BEGIN 6 */
  /* User can add his own implementation to report the file name and line number,
     ex: printf("Wrong parameters value: file %s on line %d\r\n", file, line) */
  /* USER CODE END 6 */
}
#endif /* USE_FULL_ASSERT */

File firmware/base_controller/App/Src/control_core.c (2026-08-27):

/**
  ******************************************************************************
  * @file    control_core.c
  * @brief   ControlTask cycle의 순수 구현.
  * @note    출력 결정은 언제나 "지령을 기억하고 매 cycle 새로 계산한다"이다.
  *          지난 duty가 어딘가에 남아 있다가 되살아나는 경로 자체를 만들지 않는다.
  *
  *          두 모드가 나란히 있다.
  *            개루프(duty) — 호스트가 준 per-mille를 클램프해 그대로 쓴다.
  *            폐루프(vel)  — 목표 tps를 받아 FF+PI가 duty를 만든다.
  *          모드는 마지막 duty/vel 지령이 정하고, 모드가 바뀌면 적분기를 리셋한다.
  ******************************************************************************
  */
#include "control_core.h"

#include "app_config.h"
#include "motor_output.h"

/* app_config.h의 확정값으로 초기화한다. const가 아닌 것은 튜닝 중 SWD로 덮어쓰기
   위해서다. 확정된 값은 반드시 app_config.h로 되돌려 커밋한다. */
speed_gains_t g_speed_gains_left = {
  KFF_LEFT, RUN_INTERCEPT_LEFT, SPEED_KP_LEFT, SPEED_KI_CYCLE_LEFT,
  SPEED_I_MAX_PM, MOTOR_DUTY_MAX_PM
};

speed_gains_t g_speed_gains_right = {
  KFF_RIGHT, RUN_INTERCEPT_RIGHT, SPEED_KP_RIGHT, SPEED_KI_CYCLE_RIGHT,
  SPEED_I_MAX_PM, MOTOR_DUTY_MAX_PM
};

static int32_t clamp_i32(int32_t value, int32_t limit)
{
  if (value > limit)
  {
    return limit;
  }
  if (value < -limit)
  {
    return -limit;
  }
  return value;
}

static int32_t round_to_i32(float value)
{
  return (int32_t)((value >= 0.0f) ? (value + 0.5f) : (value - 0.5f));
}

/**
  * @brief  코스팅으로 되돌린다. 목표·적분기·지령 duty를 전부 지운다.
  * @note   워치독 만료, stop, urgent stop이 전부 여기로 온다. 이 펌웨어에서 정지는 곧
  *         자유 회전이다. 목표 0에서 PI를 돌리면 error = -measured가 되어 역방향
  *         duty가 나온다. 전류 측정 수단이 없는 상태에서 그건 기어박스에 거는
  *         역토크다.
  */
static void control_coast(control_core_t *c)
{
  c->cmd_left_pm = 0;
  c->cmd_right_pm = 0;
  speed_control_set_target(&c->spd_left, 0);
  speed_control_set_target(&c->spd_right, 0);
  speed_control_reset(&c->spd_left);
  speed_control_reset(&c->spd_right);
}

/**
  * @brief  폐루프 출력을 다시 계산한다.
  * @param  advance_integrator  정상 cycle(tick_delta == 1)에서만 true.
  */
static void control_run_closed_loop(control_core_t *c, bool advance_integrator)
{
  c->cmd_left_pm = speed_control_update(&c->spd_left, &g_speed_gains_left,
                                        c->measured_tps_left, advance_integrator);
  c->cmd_right_pm = speed_control_update(&c->spd_right, &g_speed_gains_right,
                                         c->measured_tps_right, advance_integrator);
}

/**
  * @brief  워치독/fault를 반영해 이번 cycle의 출력을 정한다.
  * @note   만료 edge는 여기서 한 번만 wd_seq로 바뀐다. 관측자는 wd_seq 변화를 보고
  *         `wd` 한 줄을 만든다. ControlTask가 0을 반영한 뒤에 일어난다.
  */
static void control_commit(control_core_t *c, uint32_t now_ms, control_out_t *out)
{
  if (motor_safety_output_allowed(&c->safety, now_ms))
  {
    c->output_allowed = true;
    c->out_left_pm = c->cmd_left_pm;
    c->out_right_pm = c->cmd_right_pm;
    out->kind = CONTROL_OUT_WRITE;
    out->ccr  = motor_ccr_from_duty(c->cmd_left_pm, c->cmd_right_pm);
    return;
  }

  c->output_allowed = false;
  c->out_left_pm = 0;
  c->out_right_pm = 0;

  if (motor_safety_take_notify(&c->safety))
  {
    c->wd_seq++;
    c->wd_ms = now_ms;
  }

  /* 만료 상태에서는 목표도 적분기도 남기지 않는다. 출력이 다시 허용되는 유일한
     경로는 새 유효 명령이다. 그때 목표가 새로 실린다. */
  control_coast(c);

  if (motor_safety_faulted(&c->safety))
  {
    /* 래치된 fault에서는 CCR 0으로 그치지 않고 MOE까지 내린다. */
    out->kind = CONTROL_OUT_KILL;
    return;
  }

  out->kind = CONTROL_OUT_WRITE;
  out->ccr  = motor_ccr_from_duty(0, 0);
}

void control_core_init(control_core_t *c, uint32_t now_ms,
                       uint16_t enc_left_raw, uint16_t enc_right_raw)
{
  motor_safety_init(&c->safety, now_ms, CMD_WATCHDOG_MS);
  encoder_accum_init(&c->enc_left, ENCODER_SIGN_LEFT, enc_left_raw);
  encoder_accum_init(&c->enc_right, ENCODER_SIGN_RIGHT, enc_right_raw);
  speed_control_init(&c->spd_left);
  speed_control_init(&c->spd_right);
  c->measured_tps_left = 0.0f;
  c->measured_tps_right = 0.0f;

  c->cmd_left_pm = 0;
  c->cmd_right_pm = 0;
  c->out_left_pm = 0;
  c->out_right_pm = 0;
  c->closed_loop = false;
  c->applied_seq = 0U;
  c->tick_seq_seen = 0U;
  c->loop_count = 0U;
  c->loop_overruns = 0U;
  c->urgent_stop_count = 0U;
  c->stale_command_count = 0U;
  c->heartbeat = 0U;
  c->wd_seq = 0U;
  c->wd_ms = 0U;
  c->output_allowed = false;
}

void control_core_on_tick(control_core_t *c, uint32_t now_ms, uint32_t tick_seq,
                          uint16_t enc_left_raw, uint16_t enc_right_raw,
                          control_out_t *out)
{
  /* 부호 없는 뺄셈이라 tick_seq가 감겨도 성립한다. */
  uint32_t delta = tick_seq - c->tick_seq_seen;
  int32_t  d_left = encoder_accum_delta(&c->enc_left, enc_left_raw);
  int32_t  d_right = encoder_accum_delta(&c->enc_right, enc_right_raw);

  if (delta > 1U)
  {
    /* ISR이 여러 번 울리는 동안 한 번도 깨어나지 못했다. 병합된 만큼을 센다. */
    c->loop_overruns += (delta - 1U);
  }

  if (delta != 0U)
  {
    c->tick_seq_seen = tick_seq;
    c->loop_count++;
    c->heartbeat++;
  }

  /* 병합된 cycle에서도 델타 누적은 그대로 성립한다. 샘플 간격만 길어진다. */
  encoder_accum_update(&c->enc_left, enc_left_raw);
  encoder_accum_update(&c->enc_right, enc_right_raw);

  if (delta != 0U)
  {
    /* 병합된 표본은 여러 주기분의 델타다. tick_delta로 나누지 않으면 속도가
       그 배수만큼 튄다. 정상 경로에서는 delta == 1이므로 기존 식과 같다. */
    float scale = (float)CONTROL_RATE_HZ / (float)delta;

    c->measured_tps_left = (float)d_left * scale;
    c->measured_tps_right = (float)d_right * scale;

    if (c->closed_loop)
    {
      control_run_closed_loop(c, delta == 1U);
    }
  }

  control_commit(c, now_ms, out);
}
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

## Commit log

2026-08-27 feat: NUCLEO-F446RE 보드 단독 브링업 및 시리얼 통신 검증
2026-08-27 docs: 보드레이트 최적값 실측 정리
2026-08-27 feat: TIM2/TIM3 엔코더 인터페이스 및 틱 전송 구현
2026-08-27 docs: 엔코더 브링업 및 바퀴 틱 수 실측 정리
2026-08-27 feat: TIM1 PWM 모터 구동 및 시리얼 명령 처리·워치독 구현
2026-08-27 fix: 모터 부호 수정
    [main.c]
2026-08-27 docs: 모터 개루프 특성화 실측 데이터
    [motor-duty-tps.csv]
2026-08-27 refactor: main.c 모듈화
2026-08-27 chore: CubeMX FreeRTOS 뼈대 생성
2026-08-27 feat: FreeRTOS 정적 할당 실행 뼈대 구현 및 100Hz 제어 이식
2026-08-27 feat: 폐루프 제어 튜닝 IWDG 활성화 전
2026-08-27 feat: IWDG 활성화 및 폐루프 제어 구현 완료
2026-08-27 feat: RPi5 통신을 위한 USART1 DMA 설정
2026-08-27 feat: RPi5-Nucleo 간 UART 보드레이트 921600으로 확정
2026-08-27 feat: micro-ROS 기반 베이스 제어 인터페이스 구현
2026-08-27 feat: ROS 2 휠 오도메트리 패키지 구현
2026-08-27 feat: odom 보정
2026-08-27 feat: odom 회전 눈금 보정
    [motor-duty-tps.csv]
2026-08-27 docs: 플랫폼 이식 완료
2026-08-28 feat: 모바일 로봇 CAD 메시 및 URDF 설명 패키지 구현
    [cart_frame.stl, cart_frame_mesh.step, drive_wheel.stl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]
2026-10-30 feat: 베이스 인터페이스 KiCad 프로젝트 추가
2026-10-30 chore: 로컬 개발 산출물 gitignore 정리
2026-10-30 chore: 메모 정리
2026-10-30 feat: ArUco 인지/정렬 인터페이스 패키지 구현
2026-10-30 feat: ArUco 마커 추종 및 브링업 구현
2026-10-30 fix: usb_cam 프레임 타임스탬프 계산 패치 추가
2026-10-30 fix: MCU 축간거리를 지면 보정값으로 통일하고 odom 종료 예외 처리
2026-10-30 feat: 정렬 제어에 시야 유지 조건과 제자리 최소 회전 속도 추가
2026-10-30 feat: 시니어케어 통신 계약 추가
2026-10-30 feat: 시니어케어 ROS 메시지 추가
2026-10-30 feat: 폰 브리지와 mock 서버 구현
2026-10-30 feat: 출발·정지 mission 노드 구현
2026-10-30 feat: Firebase 텔레메트리 에이전트 구현
2026-10-30 feat: 개발 PC 데모 실행 도구 추가
2026-10-30 feat: 시니어케어 계약에 diag 스키마, idle 추적 상태, RTDB 규칙, PROTOCOL 문서 반영
2026-10-30 feat: 텔레메트리 diag 보고와 idle 추적 상태 반영
2026-10-30 feat: mission에 M3 safety 규칙 추가
2026-10-30 feat: 폰 브리지 개발 PC 데모, e2e, RPi5 배포 도구 추가
2026-10-30 feat: IMU와 배터리 전압 측정 추가
    ICM-42688-P /imu/data_raw 100 Hz, BaseStatus.supply_voltage(ADC1, VREFINT 보정).
2026-10-30 feat: imu_node(공분산 중계)와 임시 imu_link 추가
2026-10-31 fix: 부팅 시 HSE 클럭 대기 추가
2026-10-31 feat: IMU 장착 위치 실측값 반영
2026-10-31 feat: IMU 장착 자세 주행 측정값 반영
2026-10-31 feat: Xbox 패드 수동 조종 추가
2026-10-31 fix: 카메라 SHM 세그먼트 확대
2026-10-31 feat: 앱 SOS 요청·취소 메시지 추가
2026-10-31 feat: 배터리 잔량 추정과 앱 SOS 처리 추가
2026-10-31 feat: 보호자 웹 푸시 알림 추가
2026-11-01 fix: 재시작 뒤 남은 SOS 노드 정리
2026-11-10 fix: micro-ROS 빌드의 레거시 링크 fault latch 제거
2026-11-10 chore: 연구 자료 폴더 gitignore 추가
2026-11-10 feat: 자이로 융합 EKF 오도메트리 추가
2026-11-10 feat: RPLIDAR C1 연결과 SLAM 지도 작성 launch 추가
2026-11-10 chore: 명세·작업 기록 문서 제외
2026-11-10 docs: README 새로 작성
2026-11-10 chore: 하드웨어 라이선스를 CERN-OHL-P로 변경
2026-11-10 fix: 라이다 장착 자세 실측값과 SLAM 설정 보정
2026-11-10 feat: 지도 작성용 RViz 설정 추가
2026-11-11 feat: 실물 조립 기준 3D 모델과 미리보기 이미지 추가

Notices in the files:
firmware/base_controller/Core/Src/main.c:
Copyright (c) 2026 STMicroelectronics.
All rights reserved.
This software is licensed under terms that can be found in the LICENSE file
